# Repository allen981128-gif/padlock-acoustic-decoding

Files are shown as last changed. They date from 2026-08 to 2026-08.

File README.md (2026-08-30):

# Acoustic Recognition and Closed-Loop Automated Decoding of a Mechanical Combination Padlock

This repository is the version-controlled software and reproducibility snapshot associated with an MSc individual research project on controlled contact-acoustic recognition and closed-loop mechanical operation of a four-wheel combination padlock.

The repository is intended for **authorised laboratory research and dissertation examination**. It contains the final host application source, embedded-control firmware, CAD-generation scripts, the complete RQ1--RQ23 Colab notebook set, selected companion analysis scripts, and frozen runtime model assets used by the deployed research system.

## Repository status

- Repository: `padlock-acoustic-decoding`
- Submission snapshot: `dissertation-v1.0`
- Visibility at submission: **Private**
- Public release: review with the project supervisor before changing visibility.

## Contents

- `host_app/` — final Python/PySide6 acquisition, signal-review and supervised recognition application.
- `firmware/` — PlatformIO/Arduino firmware for the Adafruit Feather ESP32-S3, wheel drive, rail positioning, servo engagement, homing and acquisition timing.
- `cad/fusion_scripts/` — parameterised Autodesk Fusion 360 scripts and print-layout utilities.
- `cad/Mechanical_system_geometry.f3d` — archived Fusion 360 assembly/design file.
- `analysis/rq/` — archived Colab notebooks for RQ1--RQ23; later RQs also include the companion Python implementations where these were part of the formal analysis.
- `analysis/final_model_training/` — controlled model-family comparison on the engineered acoustic representation.
- `model_assets/` — manifest describing the deployed frozen runtime assets stored under `host_app/model_assets/`.
- `docs/` — hardware configuration, dataset structure, reproducibility notes and artifact hashes.
- `data/` — data-availability note only. Raw WAV datasets are not stored in Git.

## Deployed recognition system

The host application contains the frozen `MAIN v8` runtime used for W1, W2 and W4 acoustic ranking and the deterministic W3 physical-unlock detector. `MAIN v7` runtime assets are retained for the frozen prospective B07 evaluation and compatibility with earlier evidence.

The application is a supervised research prototype. Final physical opening is confirmed by the operator. The dissertation separates model-level ranking accuracy from end-to-end physical-unlock outcomes.

## Quick start

### Host application

1. Install Python 3.
2. Create a virtual environment.
3. Install dependencies with:
   `pip install -r host_app/requirements.txt`
4. Copy `host_app/settings.example.json` to `host_app/settings.json`.
5. Set the serial port, audio device and local dataset path for the current machine.
6. Connect the ESP32 controller and Focusrite audio interface.
7. Run `python host_app/app.py`.

The original Windows helper scripts under `host_app/` may also be used.

### Firmware

Open `firmware/` as a PlatformIO project. The target is `adafruit_feather_esp32s3`, with Arduino framework and an ESP32Servo dependency. Build and upload through PlatformIO.

### Fusion 360

The scripts under `cad/fusion_scripts/` are numbered to preserve the geometric dependency order used by the project. Start with `00_Lock_Parameters` and proceed through the required components. The archived `.f3d` file provides the realised integrated geometry.

## Research-question analysis

The formal Colab notebook used for each dissertation research question is preserved under `analysis/rq/`, from RQ1 through RQ23. These are archived research snapshots rather than a single turnkey pipeline: some notebooks reference the original Google Drive/Colab directory layout and therefore require path adaptation if rerun elsewhere. Generated bulk CSV predictions, cached features and raw WAV datasets are not duplicated in Git. See `analysis/README.md` and `analysis/RQ_INDEX.md`.

## Data

The raw acoustic datasets are archived separately because they are large and include many WAV files. Dataset v1 contains seven fixed-combination batches and is organised by batch, wheel, starting-position profile, direction, A/B repeat, ten-candidate decision and candidate run. See `docs/dataset_structure.md`.

## Reproducibility boundary

The repository preserves the configuration that can be verified from the final source and frozen runtime manifests. It does not retrospectively invent unrecovered analogue or driver settings. In particular, the exact TMC2209 microstepping/current-limit/Vref settings and absolute Focusrite gain-knob position were not reliably preserved in the final project record.

## Citation

See `CITATION.cff`. Replace the temporary author placeholder with the official dissertation author name before making the repository public.

## Licence and release

No public reuse licence is granted in this private dissertation snapshot. A public licence should be selected only if the repository is later approved for public release.

## Responsible use

This project concerns physical-security research. Use the hardware and software only on locks and equipment that you own or are explicitly authorised to test. The repository is provided for academic reproducibility and examination, not for unauthorised access.

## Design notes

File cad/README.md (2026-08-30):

# CAD and Fusion 360 source

`fusion_scripts/` contains the parameterised Fusion 360 project scripts. The numbering records geometric dependency rather than an arbitrary file list.

A typical rebuild starts with `00_Lock_Parameters` and then executes only the components required by the target assembly or print layout. Integrated scripts under `14_Integrated_Base` and `15_Print_Layout` include dependency copies required by those workflows.

`Mechanical_system_geometry.f3d` is the archived integrated Fusion design supplied with the dissertation source materials.

The `3D_print/` directory contains exported STL files supplied with the final CAD archive.

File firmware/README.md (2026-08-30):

# ESP32-S3 firmware

PlatformIO project for the mechanical actuation controller.

## Target

- Board: Adafruit Feather ESP32-S3
- Framework: Arduino
- Serial monitor: 115200 baud
- Library: `madhephaestus/ESP32Servo`

## Build

From this directory:

```bash
pio run
```

Upload through PlatformIO using the connected Feather ESP32-S3.

The repository deliberately excludes `.pio/` generated build output and machine-specific VS Code configuration.

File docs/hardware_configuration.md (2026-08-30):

# Hardware configuration

This note records the command-level hardware settings reproduced from the final source tree.

## Controller and GPIO

| Function | GPIO / logic |
|---|---:|
| Wheel motor EN | GPIO11 |
| Wheel motor STEP | GPIO12 |
| Wheel motor DIR | GPIO13 |
| Rail motor EN | GPIO6 |
| Rail motor STEP | GPIO9 |
| Rail motor DIR | GPIO10 |
| Servo signal | GPIO5 |
| Rail limit signal | GPIO18 |
| Driver enable | active-low |
| STEP idle | LOW |
| Limit released / triggered | LOW / HIGH |
| USB serial | 115200 baud |

## Motion calibration

| Parameter | Final source value |
|---|---:|
| Wheel steps per revolution | 1710 |
| Wheel steps per digit | 171 |
| Wheel step interval | 1600 us |
| STEP pulse width | 4 us |
| Driver-enable settling | 500 us |
| Rail normal step interval | 100 us |
| Homing fast interval | 200 us |
| Homing slow interval | 900 us |
| Homing backoff | 600 steps |
| Rail W1/W2/W3/W4 positions | 49500 / 62000 / 74400 / 87700 steps |
| Limit debounce | 15 ms |
| Rail settling | 100 ms |
| Servo up / down | 80 / 120 degrees |
| Servo settling | 500 ms |
| Servo PWM | 50 Hz |

## Acoustic acquisition

- 2 x AD-35 contact sensors.
- Focusrite 2i2 dual-channel interface.
- Channel 1: lock-target sensor.
- Channel 2: motor-reference sensor.
- 44.1 kHz, 24-bit PCM WAV.
- Instrument mode.
- Phantom power off.
- AIR off.
- Standard pre-roll 0.5 s.
- Standard post-roll 0.7 s.

## Reproducibility boundary

The final record does not reliably preserve TMC2209 microstepping/current-limit/Vref or the absolute Focusrite gain-knob position. These values are not reconstructed retrospectively.

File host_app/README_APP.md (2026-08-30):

# Padlock Collector App

Research-control application for the automated four-wheel padlock apparatus. The current application combines raw dual-channel acoustic data collection, manual hardware control, signal review, frozen True-Gate inference and supervised physical-unlock verification.

## Current recognition workflow

Automatic Recognition uses the frozen **TRUE-GATE MAIN v8 ACCURACY** runtime for W1, W2 and W4. Each wheel is evaluated using the Dataset-v1-compatible Digit Scan protocol: ten one-digit candidates are recorded for each CCW/CW and A/B component, and MAIN v8 fuses the resulting candidate evidence. The operator confirms the physical movement between sequential wheel decisions.

After the W1/W2/W4 Top-1 prefix is applied, W3 is searched by a continuous one-digit CCW sweep. **Physical Unlock Detector v1** evaluates each saved movement from the contact microphone using the frozen post-SCAN_END RMS/dRMS rule; a detector trigger pauses the workflow and the operator confirms whether the lock is physically open.

If a complete W3 sweep produces no confirmed opening and the minimum W1/W2/W4 MAIN-v8 margin is below the fixed pilot threshold of 0.20, the App permits one fresh randomized recognition pass. The maximum number of full recognition passes is two. Evidence-ranked Top-2 prefix fallback remains available after this bounded retry logic.

## Main application areas

- **Collection** — raw Digit Scan / Binding Scan compatible data collection with run-level metadata, event alignment and QC.
- **Manual Control** — wheel, rail and servo verification and positioning.
- **Signal Review** — inspection of completed runs without modifying raw recordings.
- **Recognition** — supervised automatic recognition plus offline scoring of MAIN-v8-compatible sessions.

## Data policy

Raw recordings are preserved. A run may contain `audio.wav`, `audio_dual.wav`, `motor_reference.wav`, `events.csv`, `metadata.json`, `quality.json` and serial logs. Normalisation, filtering, template cancellation or other experimental preprocessing should be written as derived data rather than overwriting the raw acquisition.

For Dataset-v1-compatible decisions, the grouping hierarchy is important: candidate WAVs belong to a ten-candidate decision; direction/repeat decisions belong to a profile; profiles belong to a password batch. Random WAV-level train/test splitting is not an appropriate evaluation protocol for the research models.

## Frozen model assets

`model_assets/` contains the deployed MAIN v7 and MAIN v8 runtime assets. Automatic Recognition uses MAIN v8. MAIN v7 assets are retained for historical evaluation and compatibility with earlier experiments.

Some acquisition metadata still contains the legacy internal identifier `auto_recognition_main_v7`. It is intentionally retained at this cleanup stage so existing datasets and parsers remain compatible; it does **not** indicate that current automatic scoring uses MAIN v7.

## Setup and run (Windows)

1. Install Python.
2. Run `setup_app.bat` to create `.venv` and install `requirements.txt`.
3. Connect the ESP32 and Focusrite interface.
4. Review `settings.json` for the serial port, audio device and dataset location.
5. Run `run_app.bat`.

`build_app.bat` creates a PyInstaller one-directory build under `dist/PadlockCollector/`. Build outputs are deliberately excluded from the clean source package.

## Entry points

- `app.py` — PySide6 GUI entry point.
- `main.py` — command-line collection entry point.
- `true_gate_inference.py` — frozen MAIN v8 inference implementation.
- `auto_recognition.py` — automatic-recognition state/persistence and fallback policy helpers.
- `unlock_detector_v1.py` — deterministic W3 physical-unlock detector.

## Research status

This repository is a research prototype for controlled, authorised laboratory evaluation. Model-development notebooks and historical experimental scripts are maintained separately from the final runtime source so the deployed code is not confused with the experiment archive.

## Source layout

The desktop application is intentionally split by responsibility:

- `app_window.py` — main application state and workflow coordination.
- `app_ui.py` — static page construction, navigation layout and presentation-only widget builders.
- `app_recognition_validation.py` — offline MAIN-v8 validation controls and result presentation.
- `app_theme.py` — application and modal-dialog Qt style sheets.
- `app_dialogs.py` — reusable themed dialogs and small presentation widgets.
- `app_backend.py` — hardware-facing orchestration used by the UI.
- `auto_recognition.py` — recognition-session bookkeeping, ranking and retry policy.
- `true_gate_inference.py` — frozen MAIN v8 feature extraction and inference runtime.
- `unlock_detector_v1.py` — frozen W3 physical-unlock detector.
- `decision_batch.py` — Dataset-v1 / Binding Scan plan and decision handling.

Research-model code and frozen runtime assets are kept separate from presentation-only UI code. The automatic-recognition and collection state machines remain in `app_window.py`; the extracted UI modules do not implement model or hardware decisions.

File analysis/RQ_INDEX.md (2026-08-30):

# RQ notebook index

The repository preserves one formal Colab notebook for each dissertation research question. The small `00_RQ1-4_QC_support/` directory contains the QC manifest/checks used by RQ1--RQ4.

| RQ | Archived notebook | Companion executable script |
|---:|---|---|
| 1 | `01_RQ1_Acoustic_Feasibility/01_RQ1_Acoustic_Feasibility.ipynb` | — |
| 2 | `02_RQ2_Shackle_Loading/02_RQ2_Shackle_Loading.ipynb` | — |
| 3 | `03_RQ3_Lock_vs_Motor_Noise/03_RQ3_Lock_vs_Motor_Noise.ipynb` | — |
| 4 | `04_RQ4_Actuation_Repeatability/04_RQ4_Actuation_Repeatability.ipynb` | — |
| 5 | `05_RQ5_Prev_Current_Next/05_RQ5_Prev_Current_Next.ipynb` | — |
| 6 | `06_RQ6_Context_Generalisation/06_RQ6_Context_Generalisation.ipynb` | — |
| 7 | `07_RQ7_Absolute_vs_Relative/07_RQ7_Absolute_vs_Relative.ipynb` | — |
| 8 | `08_RQ8_Temporal_Localisation/08_RQ8_Temporal_Localisation.ipynb` | — |
| 9 | `09_RQ9_Universal_CrossWheel_Event/09_RQ9_Universal_CrossWheel_Event.ipynb` | — |
| 10 | `10_RQ10_Binding_First/10_RQ10_Binding_First.ipynb` | — |
| 11 | `11_RQ11_Absolute_vs_Controlled_Ranking/11_RQ11_Absolute_vs_Controlled_Ranking.ipynb` | — |
| 12 | `12_RQ12_Shortcut_Resistant_Dataset/12_RQ12_Shortcut_Resistant_Dataset.ipynb` | — |
| 13 | `13_RQ13_Current_Only_Baseline/13_RQ13_Current_Only_Baseline.ipynb` | — |
| 14 | `14_RQ14_Direction_Handling/14_RQ14_Direction_Handling.ipynb` | — |
| 15 | `15_RQ15_Repeat_Handling/15_RQ15_Repeat_Handling.ipynb` | — |
| 16 | `16_RQ16_Channel_Ablation/16_RQ16_Channel_Ablation.ipynb` | — |
| 17 | `17_RQ17_Shared_vs_Wheel_Specific/17_RQ17_Shared_vs_Wheel_Specific.ipynb` | — |
| 18 | `18_RQ18_Engineered_vs_Raw_Waveform/18_RQ18_Engineered_vs_Raw_Waveform.ipynb` | `RQ18_raw_vs_engineered.py` |
| 19 | `19_RQ19_Cross_Password_Generalisation/19_RQ19_Cross_Password_Generalisation.ipynb` | — |
| 20 | `20_RQ20_Sequential_Prefix_Dependency/20_RQ20_Sequential_Prefix_Dependency.ipynb` | `RQ20_prefix_dependency.py` |
| 21 | `21_RQ21_Binding_Safety_Veto/21_RQ21_Binding_Safety_Veto.ipynb` | `RQ21_binding_safety_veto.py` |
| 22 | `22_RQ22_W3_Physical_Unlock_Detector/22_RQ22_W3_Physical_Unlock_Detector.ipynb` | `RQ22_unlock_detector.py` |
| 23 | `23_RQ23_Closed_Loop_Recovery/23_RQ23_Closed_Loop_Recovery.ipynb` | `RQ23_closed_loop_recovery.py` |

RQ18 additionally retains its formal protocol and report because they were already part of the controlled representation-comparison package.

Large derived outputs are intentionally excluded; the dissertation and separate project archive remain the authoritative record for reported results.

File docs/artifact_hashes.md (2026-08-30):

# Artifact hashes

## Supplied source archives

- `app.zip` — `e4c3218e8a421dcfe8f2dbb29e83967807b15b6d70c8ba11a28b6c05305f9303`
- `Machanical_motion(2).zip` — `154e0a25b5c3a4ba4408a57a68e22c67176096925e8be87d330ef1299f45fc95`
- `fusion.zip` — `53884dd44e86e21dbff98b19055643e0dce1a0179ad4a686a0aa88b6c2db2891`
- `Mechanical_system_geometry.f3d` — `28c5d45c7183937562aa9d69103dd2d38c8d5a4f45372b5da424b6eb04fbd46d`

## Frozen runtime files in this repository

- `host_app/model_assets/MAIN_v7_FOCUS_RUNTIME.json` — `0c2e2b052ae157024490bd77c8dc6458823a7c3502baaab699433835a36c9aeb`
- `host_app/model_assets/MAIN_v7_FOCUS_RUNTIME.npz` — `caedcedbaec95cebb4e15f5aa0c6f9e80bd02c785ff464303ef7819cce32fa22`
- `host_app/model_assets/MAIN_v8_ACCURACY_ENSEMBLE_RUNTIME.json` — `f71db0d14e41b624c1d1134b8892338c6ddf5fc02833677bb02999a8671320a6`
- `host_app/model_assets/MAIN_v8_ACCURACY_ENSEMBLE_RUNTIME.npz` — `b720665076ffeeea29775cc7ab04036173c7704c4e13bee16082c3bba0362c30`
- `host_app/unlock_detector_v1.py` — `2102b73c9809a73bb17923bd741f80c1256a897ee3c1c214137c9abaf3aba3d2`
- `host_app/true_gate_inference.py` — `24cec6133d07d2ea546f7dd9bc3967ffce25a3df41d977ec36eb580eb310b733`

The SHA-256 of a ZIP archive can change when an otherwise identical source tree is repackaged. The embedded MAIN v7/v8 runtime manifests therefore also preserve the source-model checkpoint hashes used by the research evidence.

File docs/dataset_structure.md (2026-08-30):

# Dataset structure

Dataset v1 is the core controlled True-Gate dataset used by the dissertation.

## Inventory

| Batch | Combination | Profiles | 10-way decisions | Candidate records |
|---|---:|---:|---:|---:|
| B01 | 2085 | 30 | 120 | 1200 |
| B02 | 4369 | 30 | 120 | 1200 |
| B03 | 5720 | 30 | 120 | 1200 |
| B04 | 6893 | 30 | 120 | 1200 |
| B05 | 7246 | 30 | 120 | 1200 |
| B06 | 8451 | 30 | 120 | 1200 |
| B07 | 9638 | 30 | 120 | 1200 |
| **Total** | **7** | **210** | **840** | **8400** |

The three acoustic-ranking wheels are W1, W2 and W4. Each wheel has ten starting-position profiles. Each profile contains CCW-A, CCW-B, CW-A and CW-B complete Digit Scans, and each scan contains ten one-digit candidate movements.

## Naming hierarchy

Example:

```text
B01_2085
B01_W1_P01
B01_W1_P01_DSV1_MP2085_CCW
B01_W1_P01_DSV1_MP2085_CCW_A
run_000001
```

Candidate WAVs are not treated as independent experimental units. The complete ten-candidate decision is the atomic ranking unit.

## Raw run layout

A typical run directory contains:

```text
run_000001/
  audio.wav
  motor_reference.wav
  audio_dual.wav
  events.csv
  serial_log.csv
  metadata.json
  quality.json
```

Raw datasets are excluded from this Git repository. They remain in the separately archived project dataset.

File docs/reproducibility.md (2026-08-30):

# Reproducibility notes

## Source snapshot

This Git repository is a cleaned dissertation snapshot assembled from the final source archives supplied for the project. Build products, local editor files, Python caches and machine-specific runtime settings are excluded.

The original uploaded source-archive SHA-256 values are recorded in `artifact_hashes.md`.

## Host application

The application source is under `host_app/`. The machine-specific `settings.json` is deliberately excluded. Copy `settings.example.json` to `settings.json` before running.

Frozen True-Gate runtime files are under `host_app/model_assets/`.

## Firmware

The PlatformIO source is under `firmware/`. The original `.pio/` build directory was removed from the repository because it contained generated binaries and machine-local PlatformIO paths. The source-level GPIO and calibration constants are preserved.

## CAD

The Fusion 360 script tree is under `cad/fusion_scripts/`. Editor metadata and Python bytecode caches are removed. The archived integrated Fusion file is stored at `cad/Mechanical_system_geometry.f3d`.

## Analysis

The complete set of formal RQ1--RQ23 Colab notebooks is included under `analysis/rq/`. Companion Python implementations are retained for RQ18 and RQ20--RQ23 where they were part of the formal analysis package. `analysis/final_model_training/` contains the controlled model-family comparison used as a separate dissertation analysis artifact.

The notebooks are preserved as executed research snapshots, so some contain the original Colab/Google Drive paths. These paths must be adapted for a different environment. Bulk derived outputs, feature caches, the full chronological experiment archive and raw acoustic datasets are maintained separately and are not duplicated into this source repository.

## Evaluation boundaries

The deployed engineering model is MAIN v8. MAIN v7 is retained because its B01-B06 freeze and prospective B07 evaluation form an important evidence boundary. The controlled final-model comparison notebook is a dissertation analysis artifact and should not be confused with the deployed runtime model.

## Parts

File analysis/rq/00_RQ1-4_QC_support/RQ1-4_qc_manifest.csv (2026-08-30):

run_num | run_id | scan_id | ordinal | wheel | direction | tension_state | metadata_correct_digit | before_code | after_code | before_digit | after_digit | truth_digit | is_true_gate | position_valid | collection_mode | action_type | sample_rate | channels | audio_duration_s | motion_duration_s | quality_valid | final_step | event_count | target_rms | target_peak | target_clipped | reference_rms | reference_peak | reference_clipped | audio_overflow | contains_non_finite | scan_start_code | scan_start_digit | transition
1 | run_000001 | 1 | 1 | 1 | CCW | UNLOADED | -1 | 4062 | 5062 | 4 | 5 | 3 | 0 | True | digit_scan | DIGIT_MOVE | 44100 | 2 | 1.4188888888888889 | 0.275576 | True | 171 | 2 | 0.005637531115795005 | 0.2095947265625 | 0 | 0.00470916141005733 | 0.1114501953125 | 0 | False | False | 4062 | 4 | 4→5
2 | run_000002 | 1 | 2 | 1 | CCW | UNLOADED | -1 | 5062 | 6062 | 5 | 6 | 3 | 0 | True | digit_scan | DIGIT_MOVE | 44100 | 2 | 1.4188888888888889 | 0.274777 | True | 171 | 2 | 0.002991250542542075 | 0.05078125 | 0 | 0.0021440908775212 | 0.030426025390625 | 0 | False | False | 4062 | 4 | 5→6
3 | run_000003 | 1 | 3 | 1 | CCW | UNLOADED | -1 | 6062 | 7062 | 6 | 7 | 3 | 0 | True | digit_scan | DIGIT_MOVE | 44100 | 2 | 1.4188888888888889 | 0.274845 | True | 171 | 2 | 0.0027844450094897744 | 0.1063232421875 | 0 | 0.0021593851287144547 | 0.0423583984375 | 0 | False | False | 4062 | 4 | 6→7
4 | run_000004 | 1 | 4 | 1 | CCW | UNLOADED | -1 | 7062 | 8062 | 7 | 8 | 3 | 0 | True | digit_scan | DIGIT_MOVE | 44100 | 2 | 1.4188888888888889 | 0.275687 | True | 171 | 2 | 0.002560386402691284 | 0.023101806640625 | 0 | 0.002146719300229423 | 0.0399169921875 | 0 | False | False | 4062 | 4 | 7→8
5 | run_000005 | 1 | 5 | 1 | CCW | UNLOADED | -1 | 8062 | 9062 | 8 | 9 | 3 | 0 | True | digit_scan | DIGIT_MOVE | 44100 | 2 | 1.4188888888888889 | 0.275161 | True | 171 | 2 | 0.0023694481258872534 | 0.026153564453125 | 0 | 0.0021257308501341286 | 0.033203125 | 0 | False | False | 4062 | 4 | 8→9
6 | run_000006 | 1 | 6 | 1 | CCW | UNLOADED | -1 | 9062 | 0062 | 9 | 0 | 3 | 0 | True | digit_scan | DIGIT_MOVE | 44100 | 2 | 1.4188888888888889 | 0.275007 | True | 171 | 2 | 0.002333423962610432 | 0.031280517578125 | 0 | 0.001950373931256082 | 0.038818359375 | 0 | False | False | 4062 | 4 | 9→0
7 | run_000007 | 1 | 7 | 1 | CCW | UNLOADED | -1 | 0062 | 1062 | 0 | 1 | 3 | 0 | True | digit_scan | DIGIT_MOVE | 44100 | 2 | 1.4188888888888889 | 0.274515 | True | 171 | 2 | 0.003263703660200908 | 0.149078369140625 | 0 | 0.002793155892242109 | 0.07208251953125 | 0 | False | False | 4062 | 4 | 0→1
8 | run_000008 | 1 | 8 | 1 | CCW | UNLOADED | -1 | 1062 | 2062 | 1 | 2 | 3 | 0 | True | digit_scan | DIGIT_MOVE | 44100 | 2 | 1.4188888888888889 | 0.273743 | True | 171 | 2 | 0.0022838427081695698 | 0.0316162109375 | 0 | 0.002393704349693637 | 0.042724609375 | 0 | False | False | 4062 | 4 | 1→2
9 | run_000009 | 1 | 9 | 1 | CCW | UNLOADED | -1 | 2062 | 3062 | 2 | 3 | 3 | 1 | True | digit_scan | DIGIT_MOVE | 44100 | 2 | 1.4188888888888889 | 0.273689 | True | 171 | 2 | 0.002236425272661216 | 0.031219482421875 | 0 | 0.002788334097189742 | 0.044342041015625 | 0 | False | False | 4062 | 4 | 2→3
10 | run_000010 | 1 | 10 | 1 | CCW | UNLOADED | -1 | 3062 | 4062 | 3 | 4 | 3 | 0 | True | digit_scan | DIGIT_MOVE | 44100 | 2 | 1.4188888888888889 | 0.273995 | True | 171 | 2 | 0.002987695229293874 | 0.08624267578125 | 0 | 0.0028132335039161645 | 0.043731689453125 | 0 | False | False | 4062 | 4 | 3→4
11 | run_000011 | 2 | 1 | 1 | CCW | LOADED | -1 | 4062 | 5062 | 4 | 5 | 3 | 0 | True | digit_scan | DIGIT_MOVE | 44100 | 2 | 1.4188888888888889 | 0.274833 | True | 171 | 2 | 0.0018397632034402047 | 0.014678955078125 | 0 | 0.0017614189437902036 | 0.0322265625 | 0 | False | False | 4062 | 4 | 4→5
12 | run_000012 | 2 | 2 | 1 | CCW | LOADED | -1 | 5062 | 6062 | 5 | 6 | 3 | 0 | True | digit_scan | DIGIT_MOVE | 44100 | 2 | 1.4188888888888889 | 0.275674 | True | 171 | 2 | 0.002069558115597964 | 0.02740478515625 | 0 | 0.00229480048244682 | 0.03948974609375 | 0 | False | False | 4062 | 4 | 5→6
13 | run_000013 | 2 | 3 | 1 | CCW | LOADED | -1 | 6062 | 7062 | 6 | 7 | 3 | 0 | True | digit_scan | DIGIT_MOVE | 44100 | 2 | 1.4188888888888889 | 0.274147 | True | 171 | 2 | 0.002329384704322375 | 0.06732177734375 | 0 | 0.0021593230496243674 | 0.036041259765625 | 0 | False | False | 4062 | 4 | 6→7
14 | run_000014 | 2 | 4 | 1 | CCW | LOADED | -1 | 7062 | 8062 | 7 | 8 | 3 | 0 | True | digit_scan | DIGIT_MOVE | 44100 | 2 | 1.4188888888888889 | 0.27473 | True | 171 | 2 | 0.0017111712506696496 | 0.018341064453125 | 0 | 0.0020794189396096943 | 0.036712646484375 | 0 | False | False | 4062 | 4 | 7→8
15 | run_000015 | 2 | 5 | 1 | CCW | LOADED | -1 | 8062 | 9062 | 8 | 9 | 3 | 0 | True | digit_scan | DIGIT_MOVE | 44100 | 2 | 1.4188888888888889 | 0.275374 | True | 171 | 2 | 0.0022543211994038117 | 0.0399169921875 | 0 | 0.002300196333098756 | 0.035736083984375 | 0 | False | False | 4062 | 4 | 8→9
16 | run_000016 | 2 | 6 | 1 | CCW | LOADED | -1 | 9062 | 0062 | 9 | 0 | 3 | 0 | True | digit_scan | DIGIT_MOVE | 44100 | 2 | 1.4188888888888889 | 0.2741 | True | 171 | 2 | 0.0016998907877740742 | 0.016204833984375 | 0 | 0.0019063074891821816 | 0.0367431640625 | 0 | False | False | 4062 | 4 | 9→0
17 | run_000017 | 2 | 7 | 1 | CCW | LOADED | -1 | 0062 | 1062 | 0 | 1 | 3 | 0 | True | digit_scan | DIGIT_MOVE | 44100 | 2 | 1.4188888888888889 | 0.273836 | True | 171 | 2 | 0.001647054535384633 | 0.013641357421875 | 0 | 0.0020152647787622458 | 0.03326416015625 | 0 | False | False | 4062 | 4 | 0→1
18 | run_000018 | 2 | 8 | 1 | CCW | LOADED | -1 | 1062 | 2062 | 1 | 2 | 3 | 0 | True | digit_scan | DIGIT_MOVE | 44100 | 2 | 1.4188888888888889 | 0.274181 | True | 171 | 2 | 0.001787466141015679 | 0.04388427734375 | 0 | 0.0021329108792978863 | 0.03082275390625 | 0 | False | False | 4062 | 4 | 1→2
19 | run_000019 | 2 | 9 | 1 | CCW | LOADED | -1 | 2062 | 3062 | 2 | 3 | 3 | 1 | True | digit_scan | DIGIT_MOVE | 44100 | 2 | 1.4188888888888889 | 0.274823 | True | 171 | 2 | 0.001510173665780895 | 0.01373291015625 | 0 | 0.0019851036441901294 | 0.033843994140625 | 0 | False | False | 4062 | 4 | 2→3
20 | run_000020 | 2 | 10 | 1 | CCW | LOADED | -1 | 3062 | 4062 | 3 | 4 | 3 | 0 | True | digit_scan | DIGIT_MOVE | 44100 | 2 | 1.4188888888888889 | 0.27474 | True | 171 | 2 | 0.0017465904436705087 | 0.0223388671875 | 0 | 0.0024863026350202848 | 0.03631591796875 | 0 | False | False | 4062 | 4 | 3→4
21 | run_000021 | 3 | 1 | 1 | CCW | LOADED | -1 | 7062 | 8062 | 7 | 8 | 3 | 0 | True | digit_scan | DIGIT_MOVE | 44100 | 2 | 1.4188888888888889 | 0.274902 | True | 171 | 2 | 0.001707387967649426 | 0.0267333984375 | 0 | 0.001816382572974742 | 0.037811279296875 | 0 | False | False | 7062 | 7 | 7→8
22 | run_000022 | 3 | 2 | 1 | CCW | LOADED | -1 | 8062 | 9062 | 8 | 9 | 3 | 0 | True | digit_scan | DIGIT_MOVE | 44100 | 2 | 1.4188888888888889 | 0.274159 | True | 171 | 2 | 0.002731075562695475 | 0.088348388671875 | 0 | 0.002143030736198428 | 0.04205322265625 | 0 | False | False | 7062 | 7 | 8→9
23 | run_000023 | 3 | 3 | 1 | CCW | LOADED | -1 | 9062 | 0062 | 9 | 0 | 3 | 0 | True | digit_scan | DIGIT_MOVE | 44100 | 2 | 1.4188888888888889 | 0.274998 | True | 171 | 2 | 0.0017799139400883333 | 0.02532958984375 | 0 | 0.0017016836321735336 | 0.036773681640625 | 0 | False | False | 7062 | 7 | 9→0
24 | run_000024 | 3 | 4 | 1 | CCW | LOADED | -1 | 0062 | 1062 | 0 | 1 | 3 | 0 | True | digit_scan | DIGIT_MOVE | 44100 | 2 | 1.4188888888888889 | 0.275547 | True | 171 | 2 | 0.0016835352113001372 | 0.019287109375 | 0 | 0.00195649027521196 | 0.031463623046875 | 0 | False | False | 7062 | 7 | 0→1
25 | run_000025 | 3 | 5 | 1 | CCW | LOADED | -1 | 1062 | 2062 | 1 | 2 | 3 | 0 | True | digit_scan | DIGIT_MOVE | 44100 | 2 | 1.4188888888888889 | 0.274345 | True | 171 | 2 | 0.001682809137673646 | 0.0186767578125 | 0 | 0.002229271866312587 | 0.029632568359375 | 0 | False | False | 7062 | 7 | 1→2
26 | run_000026 | 3 | 6 | 1 | CCW | LOADED | -1 | 2062 | 3062 | 2 | 3 | 3 | 1 | True | digit_scan | DIGIT_MOVE | 44100 | 2 | 1.4188888888888889 | 0.275609 | True | 171 | 2 | 0.0015741013684574152 | 0.01312255859375 | 0 | 0.002399374587160003 | 0.030242919921875 | 0 | False | False | 7062 | 7 | 2→3
27 | run_000027 | 3 | 7 | 1 | CCW | LOADED | -1 | 3062 | 4062 | 3 | 4 | 3 | 0 | True | digit_scan | DIGIT_MOVE | 44100 | 2 | 1.4188888888888889 | 0.274221 | True | 171 | 2 | 0.0017806185522672748 | 0.019317626953125 | 0 | 0.002142667856976961 | 0.02557373046875 | 0 | False | False | 7062 | 7 | 3→4
28 | run_000028 | 3 | 8 | 1 | CCW | LOADED | -1 | 4062 | 5062 | 4 | 5 | 3 | 0 | True | digit_scan | DIGIT_MOVE | 44100 | 2 | 1.4188888888888889 | 0.274389 | True | 171 | 2 | 0.0018575232939752097 | 0.017852783203125 | 0 | 0.002087723439068451 | 0.02978515625 | 0 | False | False | 7062 | 7 | 4→5
29 | run_000029 | 3 | 9 | 1 | CCW | LOADED | -1 | 5062 | 6062 | 5 | 6 | 3 | 0 | True | digit_scan | DIGIT_MOVE | 44100 | 2 | 1.4188888888888889 | 0.275371 | True | 171 | 2 | 0.002235311506529286 | 0.03863525390625 | 0 | 0.002296077444610458 | 0.039764404296875 | 0 | False | False | 7062 | 7 | 5→6
30 | run_000030 | 3 | 10 | 1 | CCW | LOADED | -1 | 6062 | 7062 | 6 | 7 | 3 | 0 | True | digit_scan | DIGIT_MOVE | 44100 | 2 | 1.4188888888888889 | 0.274224 | True | 171 | 2 | 0.0022962765808054483 | 0.044158935546875 | 0 | 0.002079647542752999 | 0.032562255859375 | 0 | False | False | 7062 | 7 | 6→7
31 | run_000031 | 4 | 1 | 1 | CCW | UNLOADED | -1 | 7062 | 8062 | 7 | 8 | 3 | 0 | True | digit_scan | DIGIT_MOVE | 44100 | 2 | 1.4188888888888889 | 0.274508 | True | 171 | 2 | 0.005509058749920412 | 0.185577392578125 | 0 | 0.007396982268003628 | 0.214599609375 | 0 | False | False | 7062 | 7 | 7→8
32 | run_000032 | 4 | 2 | 1 | CCW | UNLOADED | -1 | 8062 | 9062 | 8 | 9 | 3 | 0 | True | digit_scan | DIGIT_MOVE | 44100 | 2 | 1.4188888888888889 | 0.275506 | True | 171 | 2 | 0.002216910452425703 | 0.030853271484375 | 0 | 0.002121909537358355 | 0.037384033203125 | 0 | False | False | 7062 | 7 | 8→9
33 | run_000033 | 4 | 3 | 1 | CCW | UNLOADED | -1 | 9062 | 0062 | 9 | 0 | 3 | 0 | True | digit_scan | DIGIT_MOVE | 44100 | 2 | 1.4188888888888889 | 0.275479 | True | 171 | 2 | 0.00234285004846354 | 0.020599365234375 | 0 | 0.0022192944442217715 | 0.041778564453125 | 0 | False | False | 7062 | 7 | 9→0
34 | run_000034 | 4 | 4 | 1 | CCW | UNLOADED | -1 | 0062 | 1062 | 0 | 1 | 3 | 0 | True | digit_scan | DIGIT_MOVE | 44100 | 2 | 1.4188888888888889 | 0.274463 | True | 171 | 2 | 0.0019808838737398237 | 0.016754150390625 | 0 | 0.0020776791362341752 | 0.032958984375 | 0 | False | False | 7062 | 7 | 0→1
35 | run_000035 | 4 | 5 | 1 | CCW | UNLOADED | -1 | 1062 | 2062 | 1 | 2 | 3 | 0 | True | digit_scan | DIGIT_MOVE | 44100 | 2 | 1.4188888888888889 | 0.274701 | True | 171 | 2 | 0.002318094780456298 | 0.02679443359375 | 0 | 0.0022577580314196506 | 0.036895751953125 | 0 | False | False | 7062 | 7 | 1→2
36 | run_000036 | 4 | 6 | 1 | CCW | UNLOADED | -1 | 2062 | 3062 | 2 | 3 | 3 | 1 | True | digit_scan | DIGIT_MOVE | 44100 | 2 | 1.4188888888888889 | 0.274292 | True | 171 | 2 | 0.004173135065271491 | 0.137054443359375 | 0 | 0.0027659626630981587 | 0.046844482421875 | 0 | False | False | 7062 | 7 | 2→3
37 | run_000037 | 4 | 7 | 1 | CCW | UNLOADED | -1 | 3062 | 4062 | 3 | 4 | 3 | 0 | True | digit_scan | DIGIT_MOVE | 44100 | 2 | 1.4188888888888889 | 0.274525 | True | 171 | 2 | 0.003186314622175349 | 0.094146728515625 | 0 | 0.0025550518681343305 | 0.035797119140625 | 0 | False | False | 7062 | 7 | 3→4
38 | run_000038 | 4 | 8 | 1 | CCW | UNLOADED | -1 | 4062 | 5062 | 4 | 5 | 3 | 0 | True | digit_scan | DIGIT_MOVE | 44100 | 2 | 1.4188888888888889 | 0.273892 | True | 171 | 2 | 0.0030915754783501547 | 0.0709228515625 | 0 | 0.002756615503187393 | 0.050018310546875 | 0 | False | False | 7062 | 7 | 4→5
39 | run_000039 | 4 | 9 | 1 | CCW | UNLOADED | -1 | 5062 | 6062 | 5 | 6 | 3 | 0 | True | digit_scan | DIGIT_MOVE | 44100 | 2 | 1.4188888888888889 | 0.274491 | True | 171 | 2 | 0.0019358694038843025 | 0.016448974609375 | 0 | 0.00221528648018999 | 0.038055419921875 | 0 | False | False | 7062 | 7 | 5→6
40 | run_000040 | 4 | 10 | 1 | CCW | UNLOADED | -1 | 6062 | 7062 | 6 | 7 | 3 | 0 | True | digit_scan | DIGIT_MOVE | 44100 | 2 | 1.4188888888888889 | 0.275304 | True | 171 | 2 | 0.00322888458898644 | 0.096710205078125 | 0 | 0.0033981135881301964 | 0.07086181640625 | 0 | False | False | 7062 | 7 | 6→7
41 | run_000041 | 5 | 1 | 1 | CCW | UNLOADED | -1 | 0062 | 1062 | 0 | 1 | 3 | 0 | True | digit_scan | DIGIT_MOVE | 44100 | 2 | 1.3876190476190475 | 0.274675 | True | 171 | 2 | 0.0026726888943438636 | 0.0499267578125 | 0 | 0.0031602116470400765 | 0.090301513671875 | 0 | False | False | 0062 | 0 | 0→1
42 | run_000042 | 5 | 2 | 1 | CCW | UNLOADED | -1 | 1062 | 2062 | 1 | 2 | 3 | 0 | True | digit_scan | DIGIT_MOVE | 44100 | 2 | 1.4188888888888889 | 0.274918 | True | 171 | 2 | 0.003328393657596714 | 0.09893798828125 | 0 | 0.003837136870252737 | 0.063446044921875 | 0 | False | False | 0062 | 0 | 1→2
43 | run_000043 | 5 | 3 | 1 | CCW | UNLOADED | -1 | 2062 | 3062 | 2 | 3 | 3 | 1 | True | digit_scan | DIGIT_MOVE | 44100 | 2 | 1.4188888888888889 | 0.275049 | True | 171 | 2 | 0.0020124246775172386 | 0.017333984375 | 0 | 0.0022036410253656815 | 0.0279541015625 | 0 | False | False | 0062 | 0 | 2→3
44 | run_000044 | 5 | 4 | 1 | CCW | UNLOADED | -1 | 3062 | 4062 | 3 | 4 | 3 | 0 | True | digit_scan | DIGIT_MOVE | 44100 | 2 | 1.4188888888888889 | 0.275494 | True | 171 | 2 | 0.0023476446608790232 | 0.032135009765625 | 0 | 0.002353912887682856 | 0.030059814453125 | 0 | False | False | 0062 | 0 | 3→4
45 | run_000045 | 5 | 5 | 1 | CCW | UNLOADED | -1 | 4062 | 5062 | 4 | 5 | 3 | 0 | True | digit_scan | DIGIT_MOVE | 44100 | 2 | 1.4188888888888889 | 0.274453 | True | 171 | 2 | 0.0022771519122609042 | 0.0321044921875 | 0 | 0.0024187614505201136 | 0.042877197265625 | 0 | False | False | 0062 | 0 | 4→5
46 | run_000046 | 5 | 6 | 1 | CCW | UNLOADED | -1 | 5062 | 6062 | 5 | 6 | 3 | 0 | True | digit_scan | DIGIT_MOVE | 44100 | 2 | 1.4188888888888889 | 0.274251 | True | 171 | 2 | 0.002321208033009979 | 0.0205078125 | 0 | 0.002018432102963611 | 0.045135498046875 | 0 | False | False | 0062 | 0 | 5→6
47 | run_000047 | 5 | 7 | 1 | CCW | UNLOADED | -1 | 6062 | 7062 | 6 | 7 | 3 | 0 | True | digit_scan | DIGIT_MOVE | 44100 | 2 | 1.4188888888888889 | 0.274443 | True | 171 | 2 | 0.0025428097841130263 | 0.05169677734375 | 0 | 0.0022358729722664356 | 0.038299560546875 | 0 | False | False | 0062 | 0 | 6→7
48 | run_000048 | 5 | 8 | 1 | CCW | UNLOADED | -1 | 7062 | 8062 | 7 | 8 | 3 | 0 | True | digit_scan | DIGIT_MOVE | 44100 | 2 | 1.4188888888888889 | 0.275046 | True | 171 | 2 | 0.001980114535096386 | 0.020538330078125 | 0 | 0.0019433597372790071 | 0.036407470703125 | 0 | False | False | 0062 | 0 | 7→8
49 | run_000049 | 5 | 9 | 1 | CCW | UNLOADED | -1 | 8062 | 9062 | 8 | 9 | 3 | 0 | True | digit_scan | DIGIT_MOVE | 44100 | 2 | 1.4188888888888889 | 0.275421 | True | 171 | 2 | 0.0038519712383407513 | 0.132080078125 | 0 | 0.0034481270666553493 | 0.06109619140625 | 0 | False | False | 0062 | 0 | 8→9
50 | run_000050 | 5 | 10 | 1 | CCW | UNLOADED | -1 | 9062 | 0062 | 9 | 0 | 3 | 0 | True | digit_scan | DIGIT_MOVE | 44100 | 2 | 1.4188888888888889 | 0.273956 | True | 171 | 2 | 0.00320791789950148 | 0.1014404296875 | 0 | 0.003679160791250505 | 0.08428955078125 | 0 | False | False | 0062 | 0 | 9→0
51 | run_000051 | 6 | 1 | 1 | CCW | LOADED | -1 | 0062 | 1062 | 0 | 1 | 3 | 0 | True | digit_scan | DIGIT_MOVE | 44100 | 2 | 1.4188888888888889 | 0.275395 | True | 171 | 2 | 0.004464959307975348 | 0.1353759765625 | 0 | 0.006279880042100258 | 0.19384765625 | 0 | False | False | 0062 | 0 | 0→1
52 | run_000052 | 6 | 2 | 1 | CCW | LOADED | -1 | 1062 | 2062 | 1 | 2 | 3 | 0 | True | digit_scan | DIGIT_MOVE | 44100 | 2 | 1.4188888888888889 | 0.275128 | True | 171 | 2 | 0.0022060838418157492 | 0.029815673828125 | 0 | 0.002071271613931573 | 0.030609130859375 | 0 | False | False | 0062 | 0 | 1→2
53 | run_000053 | 6 | 3 | 1 | CCW | LOADED | -1 | 2062 | 3062 | 2 | 3 | 3 | 1 | True | digit_scan | DIGIT_MOVE | 44100 | 2 | 1.4188888888888889 | 0.274755 | True | 171 | 2 | 0.0022661311473603516 | 0.013031005859375 | 0 | 0.00206480591799045 | 0.03399658203125 | 0 | False | False | 0062 | 0 | 2→3
54 | run_000054 | 6 | 4 | 1 | CCW | LOADED | -1 | 3062 | 4062 | 3 | 4 | 3 | 0 | True | digit_scan | DIGIT_MOVE | 44100 | 2 | 1.4188888888888889 | 0.273836 | True | 171 | 2 | 0.0020638538149034356 | 0.039459228515625 | 0 | 0.0019925047415859753 | 0.03857421875 | 0 | False | False | 0062 | 0 | 3→4
55 | run_000055 | 6 | 5 | 1 | CCW | LOADED | -1 | 4062 | 5062 | 4 | 5 | 3 | 0 | True | digit_scan | DIGIT_MOVE | 44100 | 2 | 1.4188888888888889 | 0.274834 | True | 171 | 2 | 0.001968205625432978 | 0.017486572265625 | 0 | 0.002023920041529323 | 0.041412353515625 | 0 | False | False | 0062 | 0 | 4→5
56 | run_000056 | 6 | 6 | 1 | CCW | LOADED | -1 | 5062 | 6062 | 5 | 6 | 3 | 0 | True | digit_scan | DIGIT_MOVE | 44100 | 2 | 1.4188888888888889 | 0.274908 | True | 171 | 2 | 0.00228602464201098 | 0.0189208984375 | 0 | 0.0019864258002247216 | 0.045135498046875 | 0 | False | False | 0062 | 0 | 5→6
57 | run_000057 | 6 | 7 | 1 | CCW | LOADED | -1 | 6062 | 7062 | 6 | 7 | 3 | 0 | True | digit_scan | DIGIT_MOVE | 44100 | 2 | 1.4188888888888889 | 0.275443 | True | 171 | 2 | 0.0024046386244048895 | 0.029327392578125 | 0 | 0.002068540618989777 | 0.038482666015625 | 0 | False | False | 0062 | 0 | 6→7
58 | run_000058 | 6 | 8 | 1 | CCW | LOADED | -1 | 7062 | 8062 | 7 | 8 | 3 | 0 | True | digit_scan | DIGIT_MOVE | 44100 | 2 | 1.4188888888888889 | 0.27516 | True | 171 | 2 | 0.0021059938715126836 | 0.02032470703125 | 0 | 0.0022576703292967355 | 0.044464111328125 | 0 | False | False | 0062 | 0 | 7→8
59 | run_000059 | 6 | 9 | 1 | CCW | LOADED | -1 | 8062 | 9062 | 8 | 9 | 3 | 0 | True | digit_scan | DIGIT_MOVE | 44100 | 2 | 1.4188888888888889 | 0.275425 | True | 171 | 2 | 0.0020378029901616424 | 0.01641845703125 | 0 | 0.0021188914107424907 | 0.032073974609375 | 0 | False | False | 0062 | 0 | 8→9
60 | run_000060 | 6 | 10 | 1 | CCW | LOADED | -1 | 9062 | 0062 | 9 | 0 | 3 | 0 | True | digit_scan | DIGIT_MOVE | 44100 | 2 | 1.4188888888888889 | 0.275403 | True | 171 | 2 | 0.002235857348683627 | 0.020111083984375 | 0 | 0.002102705032309071 | 0.03082275390625 | 0 | False | False | 0062 | 0 | 9→0
61 | run_000061 | 7 | 1 | 1 | CCW | LOADED | -1 | 5062 | 6062 | 5 | 6 | 3 | 0 | True | digit_scan | DIGIT_MOVE | 44100 | 2 | 1.4188888888888889 | 0.275072 | True | 171 | 2 | 0.00226842763070831 | 0.01434326171875 | 0 | 0.0019967003331302084 | 0.0411376953125 | 0 | False | False | 5062 | 5 | 5→6
62 | run_000062 | 7 | 2 | 1 | CCW | LOADED | -1 | 6062 | 7062 | 6 | 7 | 3 | 0 | True | digit_scan | DIGIT_MOVE | 44100 | 2 | 1.3876190476190475 | 0.274435 | True | 171 | 2 | 0.0027532781652424075 | 0.026519775390625 | 0 | 0.0019453853182781488 | 0.040191650390625 | 0 | False | False | 5062 | 5 | 6→7
63 | run_000063 | 7 | 3 | 1 | CCW | LOADED | -1 | 7062 | 8062 | 7 | 8 | 3 | 0 | True | digit_scan | DIGIT_MOVE | 44100 | 2 | 1.4188888888888889 | 0.275301 | True | 171 | 2 | 0.0021310480016680914 | 0.0284423828125 | 0 | 0.001861931142798213 | 0.032012939453125 | 0 | False | False | 5062 | 5 | 7→8
64 | run_000064 | 7 | 4 | 1 | CCW | LOADED | -1 | 8062 | 9062 | 8 | 9 | 3 | 0 | True | digit_scan | DIGIT_MOVE | 44100 | 2 | 1.4188888888888889 | 0.274441 | True | 171 | 2 | 0.002020017918353251 | 0.02398681640625 | 0 | 0.002401133294514448 | 0.031005859375 | 0 | False | False | 5062 | 5 | 8→9
65 | run_000065 | 7 | 5 | 1 | CCW | LOADED | -1 | 9062 | 0062 | 9 | 0 | 3 | 0 | True | digit_scan | DIGIT_MOVE | 44100 | 2 | 1.4188888888888889 | 0.274298 | True | 171 | 2 | 0.0021574852335567636 | 0.019500732421875 | 0 | 0.0024267572070947783 | 0.033233642578125 | 0 | False | False | 5062 | 5 | 9→0
66 | run_000066 | 7 | 6 | 1 | CCW | LOADED | -1 | 0062 | 1062 | 0 | 1 | 3 | 0 | True | digit_scan | DIGIT_MOVE | 44100 | 2 | 1.4188888888888889 | 0.27442 | True | 171 | 2 | 0.0019224774345971741 | 0.01800537109375 | 0 | 0.0021503922245534835 | 0.02850341796875 | 0 | False | False | 5062 | 5 | 0→1
67 | run_000067 | 7 | 7 | 1 | CCW | LOADED | -1 | 1062 | 2062 | 1 | 2 | 3 | 0 | True | digit_scan | DIGIT_MOVE | 44100 | 2 | 1.4188888888888889 | 0.275358 | True | 171 | 2 | 0.002918506178372736 | 0.076568603515625 | 0 | 0.002584055457234921 | 0.031036376953125 | 0 | False | False | 5062 | 5 | 1→2
68 | run_000068 | 7 | 8 | 1 | CCW | LOADED | -1 | 2062 | 3062 | 2 | 3 | 3 | 1 | True | digit_scan | DIGIT_MOVE | 44100 | 2 | 1.4188888888888889 | 0.274378 | True | 171 | 2 | 0.002099177847237337 | 0.018585205078125 | 0 | 0.0017833230506812785 | 0.033447265625 | 0 | False | False | 5062 | 5 | 2→3
69 | run_000069 | 7 | 9 | 1 | CCW | LOADED | -1 | 3062 | 4062 | 3 | 4 | 3 | 0 | True | digit_scan | DIGIT_MOVE | 44100 | 2 | 1.4188888888888889 | 0.275413 | True | 171 | 2 | 0.004582328514141335 | 0.163543701171875 | 0 | 0.002909261004339103 | 0.072601318359375 | 0 | False | False | 5062 | 5 | 3→4
70 | run_000070 | 7 | 10 | 1 | CCW | LOADED | -1 | 4062 | 5062 | 4 | 5 | 3 | 0 | True | digit_scan | DIGIT_MOVE | 44100 | 2 | 1.4188888888888889 | 0.275069 | True | 171 | 2 | 0.00197625659765511 | 0.014373779296875 | 0 | 0.0020033270178732537 | 0.035888671875 | 0 | False | False | 5062 | 5 | 4→5
71 | run_000071 | 8 | 1 | 1 | CCW | UNLOADED | -1 | 5062 | 6062 | 5 | 6 | 3 | 0 | True | digit_scan | DIGIT_MOVE | 44100 | 2 | 1.4188888888888889 | 0.274587 | True | 171 | 2 | 0.005870709178727202 | 0.27239990234375 | 0 | 0.008093847538196705 | 0.24114990234375 | 0 | False | False | 5062 | 5 | 5→6
72 | run_000072 | 8 | 2 | 1 | CCW | UNLOADED | -1 | 6062 | 7062 | 6 | 7 | 3 | 0 | True | digit_scan | DIGIT_MOVE | 44100 | 2 | 1.4188888888888889 | 0.27374 | True | 171 | 2 | 0.0026156507124308168 | 0.025665283203125 | 0 | 0.0020705260591155255 | 0.0419921875 | 0 | False | False | 5062 | 5 | 6→7
73 | run_000073 | 8 | 3 | 1 | CCW | UNLOADED | -1 | 7062 | 8062 | 7 | 8 | 3 | 0 | True | digit_scan | DIGIT_MOVE | 44100 | 2 | 1.4188888888888889 | 0.273829 | True | 171 | 2 | 0.0022258221134551343 | 0.03076171875 | 0 | 0.0025220394856026026 | 0.040863037109375 | 0 | False | False | 5062 | 5 | 7→8
74 | run_000074 | 8 | 4 | 1 | CCW | UNLOADED | -1 | 8062 | 9062 | 8 | 9 | 3 | 0 | True | digit_scan | DIGIT_MOVE | 44100 | 2 | 1.4188888888888889 | 0.274641 | True | 171 | 2 | 0.002232019180246487 | 0.0240478515625 | 0 | 0.00215957113817938 | 0.03802490234375 | 0 | False | False | 5062 | 5 | 8→9
75 | run_000075 | 8 | 5 | 1 | CCW | UNLOADED | -1 | 9062 | 0062 | 9 | 0 | 3 | 0 | True | digit_scan | DIGIT_MOVE | 44100 | 2 | 1.4188888888888889 | 0.274302 | True | 171 | 2 | 0.002163795348897727 | 0.014251708984375 | 0 | 0.0021052742260978144 | 0.036163330078125 | 0 | False | False | 5062 | 5 | 9→0
76 | run_000076 | 8 | 6 | 1 | CCW | UNLOADED | -1 | 0062 | 1062 | 0 | 1 | 3 | 0 | True | digit_scan | DIGIT_MOVE | 44100 | 2 | 1.4188888888888889 | 0.274805 | True | 171 | 2 | 0.0026330945487844527 | 0.047515869140625 | 0 | 0.0025520235378284784 | 0.044891357421875 | 0 | False | False | 5062 | 5 | 0→1
77 | run_000077 | 8 | 7 | 1 | CCW | UNLOADED | -1 | 1062 | 2062 | 1 | 2 | 3 | 0 | True | digit_scan | DIGIT_MOVE | 44100 | 2 | 1.4188888888888889 | 0.275543 | True | 171 | 2 | 0.0026383675687648663 | 0.084869384765625 | 0 | 0.0024772422646202287 | 0.05596923828125 | 0 | False | False | 5062 | 5 | 1→2
78 | run_000078 | 8 | 8 | 1 | CCW | UNLOADED | -1 | 2062 | 3062 | 2 | 3 | 3 | 1 | True | digit_scan | DIGIT_MOVE | 44100 | 2 | 1.4188888888888889 | 0.274197 | True | 171 | 2 | 0.0039541944108622135 | 0.119659423828125 | 0 | 0.0025428511020788866 | 0.036834716796875 | 0 | False | False | 5062 | 5 | 2→3
79 | run_000079 | 8 | 9 | 1 | CCW | UNLOADED | -1 | 3062 | 4062 | 3 | 4 | 3 | 0 | True | digit_scan | DIGIT_MOVE | 44100 | 2 | 1.4188888888888889 | 0.274351 | True | 171 | 2 | 0.0022773869232812207 | 0.034881591796875 | 0 | 0.0020930665206285236 | 0.039337158203125 | 0 | False | False | 5062 | 5 | 3→4
80 | run_000080 | 8 | 10 | 1 | CCW | UNLOADED | -1 | 4062 | 5062 | 4 | 5 | 3 | 0 | True | digit_scan | DIGIT_MOVE | 44100 | 2 | 1.4188888888888889 | 0.2752 | True | 171 | 2 | 0.00300738683468891 | 0.11724853515625 | 0 | 0.002448473749029969 | 0.03460693359375 | 0 | False | False | 5062 | 5 | 4→5
81 | run_000081 | 9 | 1 | 1 | CCW | UNLOADED | -1 | 8062 | 9062 | 8 | 9 | 3 | 0 | True | digit_scan | DIGIT_MOVE | 44100 | 2 | 1.4188888888888889 | 0.275064 | True | 171 | 2 | 0.00257264840312332 | 0.05242919921875 | 0 | 0.0033012495260028706 | 0.092041015625 | 0 | False | False | 8062 | 8 | 8→9
82 | run_000082 | 9 | 2 | 1 | CCW | UNLOADED | -1 | 9062 | 0062 | 9 | 0 | 3 | 0 | True | digit_scan | DIGIT_MOVE | 44100 | 2 | 1.4188888888888889 | 0.274451 | True | 171 | 2 | 0.0037130402951169985 | 0.1092529296875 | 0 | 0.004677929784301648 | 0.093994140625 | 0 | False | False | 8062 | 8 | 9→0
83 | run_000083 | 9 | 3 | 1 | CCW | UNLOADED | -1 | 0062 | 1062 | 0 | 1 | 3 | 0 | True | digit_scan | DIGIT_MOVE | 44100 | 2 | 1.4188888888888889 | 0.275499 | True | 171 | 2 | 0.0027897341076867977 | 0.093597412109375 | 0 | 0.002357670511258696 | 0.026519775390625 | 0 | False | False | 8062 | 8 | 0→1
84 | run_000084 | 9 | 4 | 1 | CCW | UNLOADED | -1 | 1062 | 2062 | 1 | 2 | 3 | 0 | True | digit_scan | DIGIT_MOVE | 44100 | 2 | 1.4188888888888889 | 0.275268 | True | 171 | 2 | 0.002443136007510827 | 0.068359375 | 0 | 0.002364598461214437 | 0.0360107421875 | 0 | False | False | 8062 | 8 | 1→2
85 | run_000085 | 9 | 5 | 1 | CCW | UNLOADED | -1 | 2062 | 3062 | 2 | 3 | 3 | 1 | True | digit_scan | DIGIT_MOVE | 44100 | 2 | 1.4188888888888889 | 0.273815 | True | 171 | 2 | 0.0018105179948013598 | 0.017120361328125 | 0 | 0.001910929583831269 | 0.041656494140625 | 0 | False | False | 8062 | 8 | 2→3
86 | run_000086 | 9 | 6 | 1 | CCW | UNLOADED | -1 | 3062 | 4062 | 3 | 4 | 3 | 0 | True | digit_scan | DIGIT_MOVE | 44100 | 2 | 1.4188888888888889 | 0.275131 | True | 171 | 2 | 0.002757694616197051 | 0.044921875 | 0 | 0.0021355630914223055 | 0.0406494140625 | 0 | False | False | 8062 | 8 | 3→4
87 | run_000087 | 9 | 7 | 1 | CCW | UNLOADED | -1 | 4062 | 5062 | 4 | 5 | 3 | 0 | True | digit_scan | DIGIT_MOVE | 44100 | 2 | 1.4188888888888889 | 0.274961 | True | 171 | 2 | 0.0020337564714522816 | 0.019134521484375 | 0 | 0.0020650648065097233 | 0.0338134765625 | 0 | False | False | 8062 | 8 | 4→5
88 | run_000088 | 9 | 8 | 1 | CCW | UNLOADED | -1 | 5062 | 6062 | 5 | 6 | 3 | 0 | True | digit_scan | DIGIT_MOVE | 44100 | 2 | 1.4188888888888889 | 0.275697 | True | 171 | 2 | 0.002245870060537114 | 0.02850341796875 | 0 | 0.0027580750858132055 | 0.0560302734375 | 0 | False | False | 8062 | 8 | 5→6
89 | run_000089 | 9 | 9 | 1 | CCW | UNLOADED | -1 | 6062 | 7062 | 6 | 7 | 3 | 0 | True | digit_scan | DIGIT_MOVE | 44100 | 2 | 1.4188888888888889 | 0.274726 | True | 171 | 2 | 0.0021121962383958085 | 0.022735595703125 | 0 | 0.0030125778938331496 | 0.043731689453125 | 0 | False | False | 8062 | 8 | 6→7
90 | run_000090 | 9 | 10 | 1 | CCW | UNLOADED | -1 | 7062 | 8062 | 7 | 8 | 3 | 0 | True | digit_scan | DIGIT_MOVE | 44100 | 2 | 1.4188888888888889 | 0.274966 | True | 171 | 2 | 0.002551265937349672 | 0.086456298828125 | 0 | 0.0028220705252322864 | 0.044708251953125 | 0 | False | False | 8062 | 8 | 7→8
91 | run_000091 | 10 | 1 | 1 | CCW | LOADED | -1 | 8062 | 9062 | 8 | 9 | 3 | 0 | True | digit_scan | DIGIT_MOVE | 44100 | 2 | 1.4188888888888889 | 0.274206 | True | 171 | 2 | 0.004111504476960084 | 0.117095947265625 | 0 | 0.007810010432855211 | 0.305419921875 | 0 | False | False | 8062 | 8 | 8→9
92 | run_000092 | 10 | 2 | 1 | CCW | LOADED | -1 | 9062 | 0062 | 9 | 0 | 3 | 0 | True | digit_scan | DIGIT_MOVE | 44100 | 2 | 1.4188888888888889 | 0.275021 | True | 171 | 2 | 0.002268059132710137 | 0.019012451171875 | 0 | 0.0024909915042457846 | 0.0379638671875 | 0 | False | False | 8062 | 8 | 9→0
93 | run_000093 | 10 | 3 | 1 | CCW | LOADED | -1 | 0062 | 1062 | 0 | 1 | 3 | 0 | True | digit_scan | DIGIT_MOVE | 44100 | 2 | 1.4188888888888889 | 0.274165 | True | 171 | 2 | 0.002086358808322491 | 0.015411376953125 | 0 | 0.002084113214787859 | 0.037933349609375 | 0 | False | False | 8062 | 8 | 0→1
94 | run_000094 | 10 | 4 | 1 | CCW | LOADED | -1 | 1062 | 2062 | 1 | 2 | 3 | 0 | True | digit_scan | DIGIT_MOVE | 44100 | 2 | 1.4188888888888889 | 0.27457 | True | 171 | 2 | 0.002126402660748133 | 0.036865234375 | 0 | 0.002205220493852931 | 0.03875732421875 | 0 | False | False | 8062 | 8 | 1→2
95 | run_000095 | 10 | 5 | 1 | CCW | LOADED | -1 | 2062 | 3062 | 2 | 3 | 3 | 1 | True | digit_scan | DIGIT_MOVE | 44100 | 2 | 1.4188888888888889 | 0.273977 | True | 171 | 2 | 0.0017753385901424883 | 0.013427734375 | 0 | 0.001854908467988959 | 0.040283203125 | 0 | False | False | 8062 | 8 | 2→3
96 | run_000096 | 10 | 6 | 1 | CCW | LOADED | -1 | 3062 | 4062 | 3 | 4 | 3 | 0 | True | digit_scan | DIGIT_MOVE | 44100 | 2 | 1.4188888888888889 | 0.274853 | True | 171 | 2 | 0.004851340982303384 | 0.16943359375 | 0 | 0.003053961953367257 | 0.069366455078125 | 0 | False | False | 8062 | 8 | 3→4
97 | run_000097 | 10 | 7 | 1 | CCW | LOADED | -1 | 4062 | 5062 | 4 | 5 | 3 | 0 | True | digit_scan | DIGIT_MOVE | 44100 | 2 | 1.4188888888888889 | 0.275526 | True | 171 | 2 | 0.0016692402796008533 | 0.013916015625 | 0 | 0.00186256519351851 | 0.034454345703125 | 0 | False | False | 8062 | 8 | 4→5
98 | run_000098 | 10 | 8 | 1 | CCW | LOADED | -1 | 5062 | 6062 | 5 | 6 | 3 | 0 | True | digit_scan | DIGIT_MOVE | 44100 | 2 | 1.4188888888888889 | 0.274647 | True | 171 | 2 | 0.0018621027523034843 | 0.021820068359375 | 0 | 0.0020932544699009425 | 0.0323486328125 | 0 | False | False | 8062 | 8 | 5→6
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

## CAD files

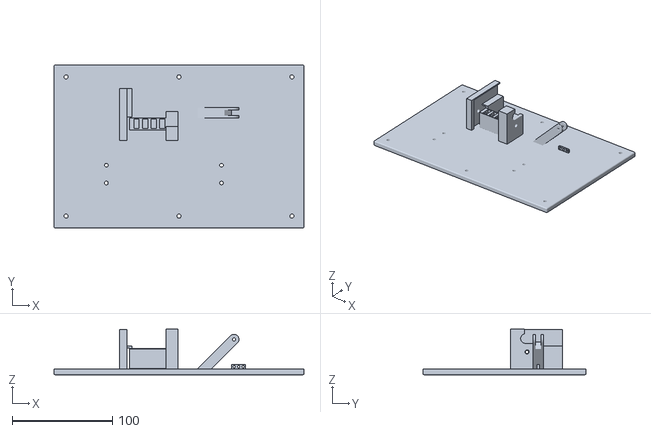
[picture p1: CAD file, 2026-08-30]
cad/fusion_scripts/3D_print/Base.stl
249.0 x 162.6 x 45.4

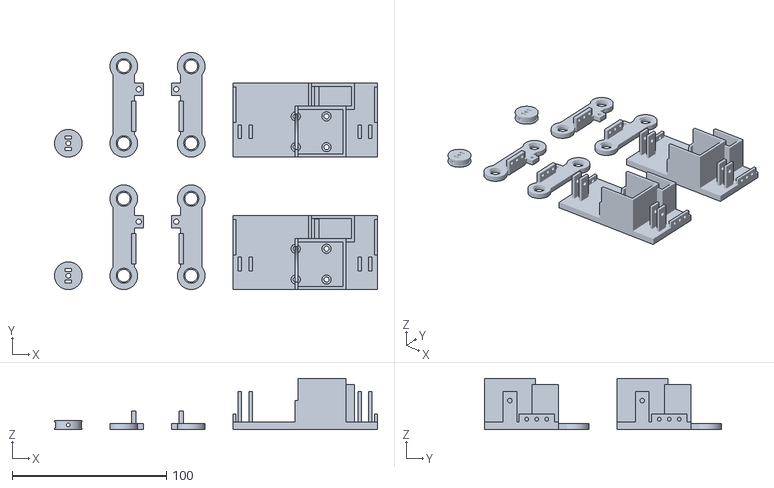
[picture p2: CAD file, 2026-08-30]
cad/fusion_scripts/3D_print/3d_print_component_v2.stl
209.7 x 154.0 x 33.2

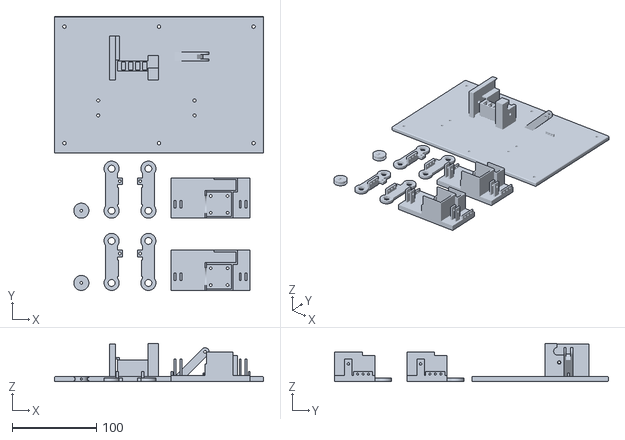
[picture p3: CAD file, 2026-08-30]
cad/fusion_scripts/3D_print/Component.stl
249.0 x 326.1 x 45.4

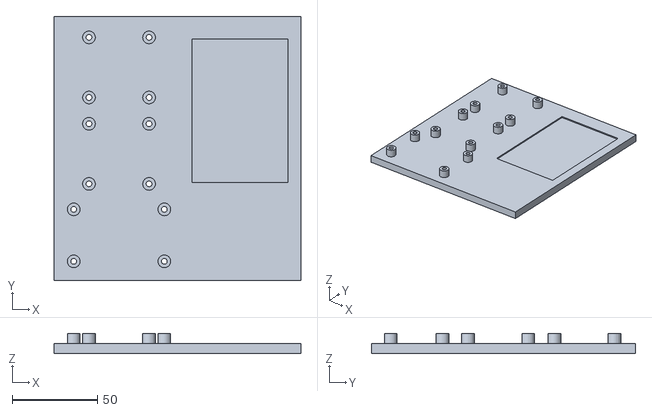
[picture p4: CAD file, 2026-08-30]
cad/fusion_scripts/3D_print/PCB_base.stl
145.0 x 155.0 x 12.0

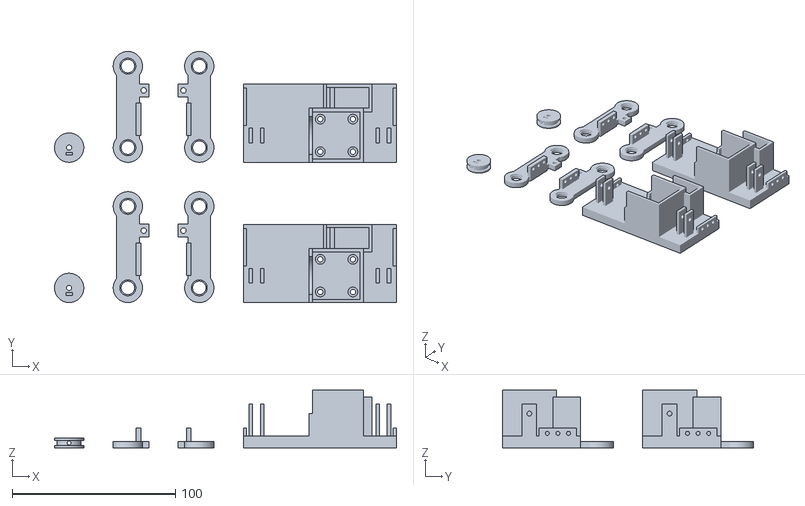
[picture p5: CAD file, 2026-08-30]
cad/fusion_scripts/3D_print/3d_print_component.stl
209.7 x 154.0 x 35.3

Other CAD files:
cad/Mechanical_system_geometry.f3d

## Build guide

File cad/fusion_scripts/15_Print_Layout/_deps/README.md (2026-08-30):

# Print-layout source dependencies

`15_Print_Layout` reconstructs the minimum assembly needed to generate the printable moving-base geometry before copying bodies into the print layout.

Generation order:

1. `00_Lock_Parameters.py`
2. `01_Passive_Shaft_Support.py`
3. `02_Padlock_Reference.py`
4. `03_Drive_Head.py`
5. `04_X_Axis_Linear_Rail.py`
6. `05_MG92B_Servo_Reference.py`
7. `07_Drive_Head_Mounting_Base_and_Limiters.py`
8. `10_O_Ring_Press_Wheel_Hub.py`
9. `11_Swing_Arm.py`

The 02/03/04/05/07/10/11 modules remain the local snapshots used by the print-layout workflow. P7.5 adds canonical 00 parameters and the passive support because the previous print-only path started directly at the padlock reference and could therefore use stale fallback dimensions. The only adaptation in the added 00/01 copies is routing status/error messages through the parent script's silent-message hook.

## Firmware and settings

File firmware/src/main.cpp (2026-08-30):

#include <Arduino.h>

#include "AcquisitionFlow.h"
#include "Calibration.h"
#include "HardwareConfig.h"
#include "LimitSwitch.h"
#include "RailController.h"
#include "SafetyController.h"
#include "SerialProtocol.h"
#include "ServoLift.h"
#include "StepperAxis.h"
#include "WheelController.h"

namespace
{
StepperAxis wheelAxis(
    Pins::WHEEL_EN,
    Pins::WHEEL_STEP,
    Pins::WHEEL_DIR,
    Calibration::WHEEL_CW_IS_HIGH
);

StepperAxis railAxis(
    Pins::RAIL_EN,
    Pins::RAIL_STEP,
    Pins::RAIL_DIR,
    Calibration::RAIL_FORWARD_IS_HIGH
);

LimitSwitch railLimit(
    Pins::RAIL_LIMIT,
    LogicLevels::LIMIT_TRIGGERED
);

ServoLift servoLift(Pins::SERVO);

WheelController wheelController(wheelAxis);

RailController railController(
    railAxis,
    railLimit
);

SerialProtocol serialProtocol(Serial);

SafetyController safetyController(
    wheelController,
    railController,
    servoLift,
    railLimit
);

AcquisitionFlow acquisitionFlow(
    wheelController,
    railController,
    servoLift,
    railLimit,
    serialProtocol,
    safetyController
);

void setSafeBootOutputs()
{
    // Disable the wheel driver
    pinMode(Pins::WHEEL_EN, OUTPUT);
    digitalWrite(
        Pins::WHEEL_EN,
        LogicLevels::DRIVER_DISABLE
    );

    pinMode(Pins::WHEEL_STEP, OUTPUT);
    digitalWrite(
        Pins::WHEEL_STEP,
        LogicLevels::STEP_IDLE
    );

    pinMode(Pins::WHEEL_DIR, OUTPUT);
    digitalWrite(Pins::WHEEL_DIR, LOW);

    // Disable the rail driver
    pinMode(Pins::RAIL_EN, OUTPUT);
    digitalWrite(
        Pins::RAIL_EN,
        LogicLevels::DRIVER_DISABLE
    );

    pinMode(Pins::RAIL_STEP, OUTPUT);
    digitalWrite(
        Pins::RAIL_STEP,
        LogicLevels::STEP_IDLE
    );

    pinMode(Pins::RAIL_DIR, OUTPUT);
    digitalWrite(Pins::RAIL_DIR, LOW);
}
}

void setup()
{
    setSafeBootOutputs();

    Serial.begin(Communication::SERIAL_BAUD);

    const uint32_t waitStartedAt = millis();

    while (!Serial &&
           millis() - waitStartedAt < 3000)
    {
        delay(10);
    }

    acquisitionFlow.begin();
}

void loop()
{
    acquisitionFlow.update();

    static uint32_t lastYieldMs = 0;
    const uint32_t now = millis();

    if (now - lastYieldMs >= 100)
    {
        lastYieldMs = now;
        delay(1);
    }
}

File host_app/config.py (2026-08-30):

from dataclasses import dataclass, field
from pathlib import Path


PROJECT_DIR = Path(__file__).resolve().parent


# Unified wheel calibration validated on the current mechanism.
# One visible digit = 171 motor steps; one full revolution = 1710 steps.
WHEEL_STEPS_PER_REV = 1710
WHEEL_STEPS_PER_DIGIT = WHEEL_STEPS_PER_REV // 10

# Binding Sweep uses the same physical calibration as discrete digit moves.
BINDING_SWEEP_STEPS_PER_REV = WHEEL_STEPS_PER_REV
BINDING_SWEEP_STEPS_PER_SECTOR = (
    BINDING_SWEEP_STEPS_PER_REV // 10
)

# Controlled binding-reference sweep: start one digit after the known true
# gate and traverse eight sectors, stopping one digit before the gate.
# This excludes both entry into and exit from the true gate.
BINDING_REFERENCE_SWEEP_SECTORS = 8
BINDING_REFERENCE_SWEEP_STEPS = (
    BINDING_REFERENCE_SWEEP_SECTORS * WHEEL_STEPS_PER_DIGIT
)
BINDING_REFERENCE_SWEEP_SECTOR_STEPS = WHEEL_STEPS_PER_DIGIT

# Wide local probe. The wheel is pre-positioned by -A, swept continuously
# between -A and +A for N cycles, then returned to the centre. The net
# displacement is zero and the default amplitude stays inside one 171-step
# digit sector with a 20-step margin on each side.
WIDE_PROBE_DEFAULT_AMPLITUDE_STEPS = 65
WIDE_PROBE_MIN_AMPLITUDE_STEPS = 20
WIDE_PROBE_MAX_AMPLITUDE_STEPS = 80
WIDE_PROBE_DEFAULT_CYCLES = 4
WIDE_PROBE_MIN_CYCLES = 1
WIDE_PROBE_MAX_CYCLES = 8


@dataclass(frozen=True)
class SerialConfig:
    port: str = "COM4"
    baud_rate: int = 115_200
    read_timeout_s: float = 0.1
    write_timeout_s: float = 1.0
    startup_wait_s: float = 2.0


@dataclass(frozen=True)
class AudioConfig:
    device_name: str = "Focusrite"
    sample_rate: int = 44_100

    # Focusrite WASAPI exposes analogue inputs 1-2 and loopback 1-2.
    capture_channels: int = 4

    # Zero-based analogue input mapping.
    target_channel: int = 0
    reference_channel: int = 1

    dtype: str = "float32"
    block_size: int = 0
    wav_subtype: str = "PCM_24"
    pre_roll_s: float = 0.5
    post_roll_s: float = 0.7


@dataclass(frozen=True)
class TimeoutConfig:
    ping_s: float = 5.0
    status_s: float = 5.0
    prepare_s: float = 60.0
    scan_start_s: float = 5.0
    scan_end_s: float = 30.0
    done_s: float = 15.0
    stop_s: float = 5.0


@dataclass(frozen=True)
class StorageConfig:
    dataset_dir: Path = PROJECT_DIR / "dataset"
    raw_dir_name: str = "raw"
    rejected_dir_name: str = "rejected"
    logs_dir_name: str = "logs"

    # audio.wav remains the mono lock-target file for compatibility.
    audio_filename: str = "audio.wav"
    reference_audio_filename: str = "motor_reference.wav"
    dual_audio_filename: str = "audio_dual.wav"
    events_filename: str = "events.csv"
    metadata_filename: str = "metadata.json"
    quality_filename: str = "quality.json"

    @property
    def raw_dir(self) -> Path:
        return self.dataset_dir / self.raw_dir_name

    @property
    def rejected_dir(self) -> Path:
        return self.dataset_dir / self.rejected_dir_name

    @property
    def logs_dir(self) -> Path:
        return self.dataset_dir / self.logs_dir_name


@dataclass(frozen=True)
class QualityConfig:
    expected_digit_boundaries: int = 0
    expected_final_step: int = WHEEL_STEPS_PER_DIGIT
    clipping_level: float = 0.999
    max_clipped_ratio: float = 0.001
    minimum_rms: float = 1e-5
    minimum_duration_s: float = 1.0


@dataclass(frozen=True)
class SessionConfig:
    plan_file: Path = PROJECT_DIR / "collection_plan.csv"
    require_confirmation: bool = True
    pause_between_runs_s: float = 1.0


@dataclass(frozen=True)
class AppConfig:
    serial: SerialConfig = field(default_factory=SerialConfig)
    audio: AudioConfig = field(default_factory=AudioConfig)
    timeouts: TimeoutConfig = field(default_factory=TimeoutConfig)
    storage: StorageConfig = field(default_factory=StorageConfig)
    quality: QualityConfig = field(default_factory=QualityConfig)
    session: SessionConfig = field(default_factory=SessionConfig)


CONFIG = AppConfig()


def ensure_storage_directories(
    config: AppConfig = CONFIG,
) -> None:
    config.storage.raw_dir.mkdir(
        parents=True,
        exist_ok=True,
    )
    config.storage.rejected_dir.mkdir(
        parents=True,
        exist_ok=True,
    )
    config.storage.logs_dir.mkdir(
        parents=True,
        exist_ok=True,
    )

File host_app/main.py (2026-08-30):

from __future__ import annotations

import argparse
from dataclasses import replace
from pathlib import Path

from acquisition_controller import AcquisitionController
from audio_recorder import AudioRecorder, AudioRecorderError
from config import CONFIG, ensure_storage_directories
from device_discovery import (
    DeviceDiscoveryError,
    find_audio_input,
    find_serial_port,
    print_devices,
)
from models import RunStatus
from quality_control import QualityControl
from run_writer import RunWriter
from serial_client import SerialClient, SerialClientError
from session_controller import (
    CollectionPlanError,
    SessionController,
)


def parse_arguments() -> argparse.Namespace:
    parser = argparse.ArgumentParser(
        description="Padlock audio data collector"
    )

    parser.add_argument(
        "--list-devices",
        action="store_true",
        help="List serial and audio devices",
    )

    parser.add_argument(
        "--session-id",
        type=str,
        default=None,
        help="Session folder name",
    )

    parser.add_argument(
        "--plan",
        type=Path,
        default=None,
        help="Collection plan CSV path",
    )

    parser.add_argument(
        "--serial-port",
        type=str,
        default=None,
        help="ESP32 serial port",
    )

    parser.add_argument(
        "--audio-device",
        type=int,
        default=None,
        help="Focusrite input device index",
    )

    parser.add_argument(
        "--expected-final-step",
        type=int,
        default=None,
        help="Expected wheel steps per digit",
    )

    parser.add_argument(
        "--continuous",
        action="store_true",
        help="Run without confirmation between runs",
    )

    return parser.parse_args()


def main() -> int:
    args = parse_arguments()

    if args.list_devices:
        print_devices()
        return 0

    if (
        args.expected_final_step is not None
        and args.expected_final_step <= 0
    ):
        print(
            "Configuration error: "
            "--expected-final-step must be positive"
        )
        return 1

    app_config = CONFIG

    if args.continuous:
        app_config = replace(
            app_config,
            session=replace(
                app_config.session,
                require_confirmation=False,
            ),
        )

    ensure_storage_directories(app_config)

    try:
        serial_port = (
            args.serial_port
            if args.serial_port is not None
            else find_serial_port(app_config.serial)
        )

        audio_device = (
            args.audio_device
            if args.audio_device is not None
            else find_audio_input(
                app_config.audio
            ).index
        )

        print(f"Serial port: {serial_port}")
        print(f"Audio device index: {audio_device}")

        with SerialClient(
            config=app_config.serial,
            port=serial_port,
        ) as serial_client:
            audio_recorder = AudioRecorder(
                config=app_config.audio,
                device_index=audio_device,
            )

            run_writer = RunWriter(
                storage_config=app_config.storage,
                audio_config=app_config.audio,
            )

            quality_control = QualityControl(
                config=app_config.quality,
            )

            acquisition_controller = (
                AcquisitionController(
                    serial_client=serial_client,
                    audio_recorder=audio_recorder,
                    run_writer=run_writer,
                    quality_control=quality_control,
                    config=app_config,
                    expected_final_step=(
                        args.expected_final_step
                    ),
                )
            )

            session_controller = SessionController(
                acquisition_controller=(
                    acquisition_controller
                ),
                config=app_config,
            )

            results = session_controller.run_session(
                session_id=args.session_id,
                plan_path=args.plan,
            )

    except KeyboardInterrupt:
        print()
        print("Collection stopped by operator")
        return 130

    except (
        AudioRecorderError,
        CollectionPlanError,
        DeviceDiscoveryError,
        SerialClientError,
        ValueError,
    ) as exc:
        print(f"Collection error: {exc}")
        return 1

    valid_count = sum(
        result.status is RunStatus.VALID
        for result in results
    )

    rejected_count = sum(
        result.status is RunStatus.REJECTED
        for result in results
    )

    failed_count = len(results) - (
        valid_count + rejected_count
    )

    print()
    print("Session finished")
    print(f"Valid runs: {valid_count}")
    print(f"Rejected runs: {rejected_count}")
    print(f"Failed or aborted runs: {failed_count}")

    return 0 if rejected_count == 0 and failed_count == 0 else 1


if __name__ == "__main__":
    raise SystemExit(main())

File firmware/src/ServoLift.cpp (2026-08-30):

#include "ServoLift.h"

#include "Calibration.h"

ServoLift::ServoLift(uint8_t pin)
    : pin_(pin)
{
}

void ServoLift::begin()
{
    if (servo_.attached())
    {
        servo_.detach();
    }

    attached_ = false;
    busy_ = false;
    moveCompleted_ = false;
    commandedAngle_ = -1;
    settleDeadlineMs_ = 0;
}

void ServoLift::update()
{
    if (!busy_)
    {
        return;
    }

    const uint32_t now = millis();

    if (!timeReached(now, settleDeadlineMs_))
    {
        return;
    }

    busy_ = false;
    moveCompleted_ = true;
}

bool ServoLift::moveUp()
{
    if (!Calibration::servoConfigured())
    {
        return false;
    }

    return startMove(Calibration::SERVO_UP_ANGLE);
}

bool ServoLift::moveDown()
{
    if (!Calibration::servoConfigured())
    {
        return false;
    }

    return startMove(Calibration::SERVO_DOWN_ANGLE);
}

bool ServoLift::moveToAngle(int angle)
{
    return startMove(angle);
}

bool ServoLift::isAttached() const
{
    return attached_;
}

bool ServoLift::isBusy() const
{
    return busy_;
}

bool ServoLift::isUp() const
{
    if (!Calibration::servoConfigured())
    {
        return false;
    }

    return attached_ &&
           !busy_ &&
           commandedAngle_ == Calibration::SERVO_UP_ANGLE;
}

bool ServoLift::isDown() const
{
    if (!Calibration::servoConfigured())
    {
        return false;
    }

    return attached_ &&
           !busy_ &&
           commandedAngle_ == Calibration::SERVO_DOWN_ANGLE;
}

bool ServoLift::takeMoveCompleted()
{
    const bool completed = moveCompleted_;
    moveCompleted_ = false;

    return completed;
}

int ServoLift::currentCommandedAngle() const
{
    return commandedAngle_;
}

bool ServoLift::startMove(int angle)
{
    if (angle < 0 || angle > 180)
    {
        return false;
    }

    if (!attached_)
    {
        servo_.setPeriodHertz(
            Calibration::SERVO_FREQUENCY_HZ
        );

        servo_.attach(
            pin_,
            Calibration::SERVO_MIN_PULSE_US,
            Calibration::SERVO_MAX_PULSE_US
        );

        attached_ = servo_.attached();

        if (!attached_)
        {
            return false;
        }
    }

    servo_.write(angle);

    commandedAngle_ = angle;
    busy_ = true;
    moveCompleted_ = false;

    settleDeadlineMs_ =
        millis() + Calibration::SERVO_SETTLE_MS;

    return true;
}

bool ServoLift::timeReached(
    uint32_t now,
    uint32_t target
)
{
    return static_cast<int32_t>(now - target) >= 0;
}

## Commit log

2026-08-30 Dissertation submission snapshot
    [3d_print_component.stl, 3d_print_component_v2.stl, Base.stl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]
2026-08-30 Flatten repository structure
    [3d_print_component.stl, 3d_print_component_v2.stl, Base.stl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]
